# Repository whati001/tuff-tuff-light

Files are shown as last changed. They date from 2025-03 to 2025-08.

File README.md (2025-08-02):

# 🚜 Wireless BLE Trailer Light System for Tractors

A robust, modular, and completely wireless trailer lighting system designed for agricultural machinery, utilizing BLE communication. 
Built on the **nRF52840 SoC** and developed with the **Zephyr RTOS**, this project includes custom-designed PCBs and 3D printed enclosures for reliable field use.
The choose design enables seamless connectivity without complicated pairing procedures and also allows to connect up to infinite receiver lights to a single sender.  

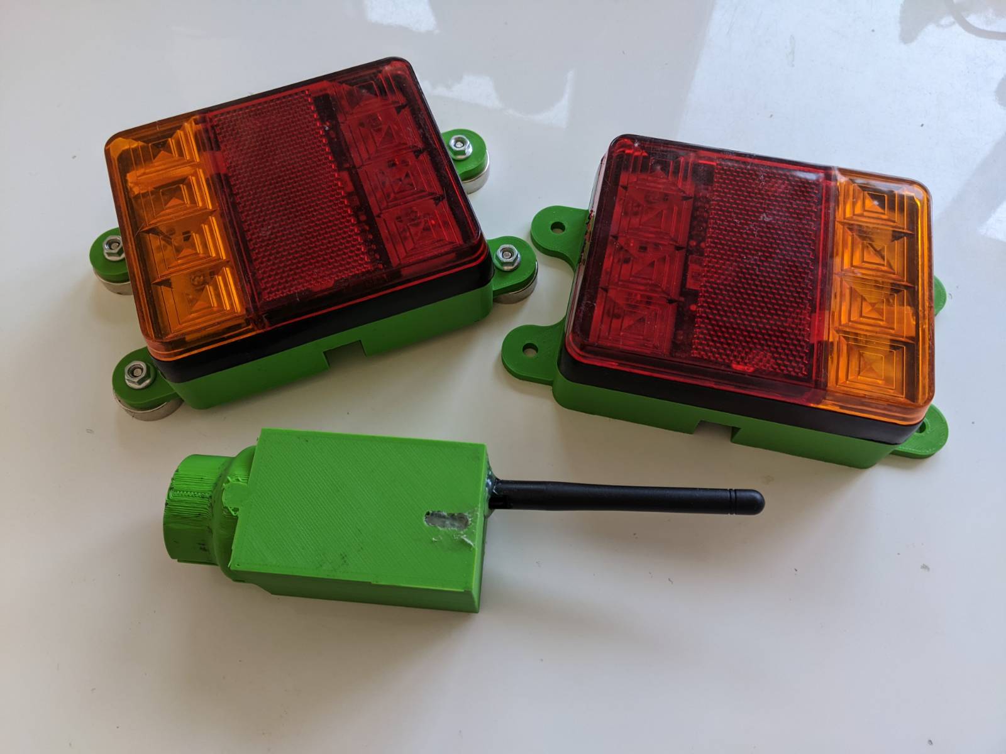
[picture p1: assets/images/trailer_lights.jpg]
Trailer Light Units

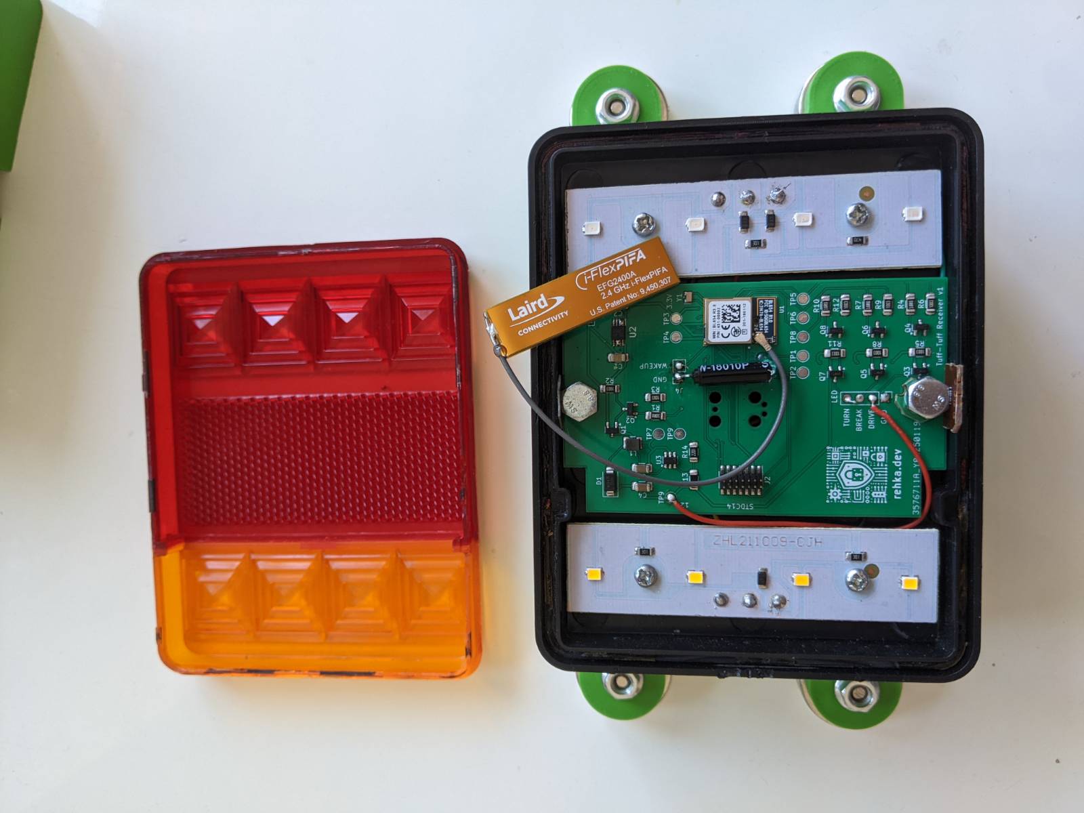
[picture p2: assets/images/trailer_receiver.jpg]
Trailer Light Receiver

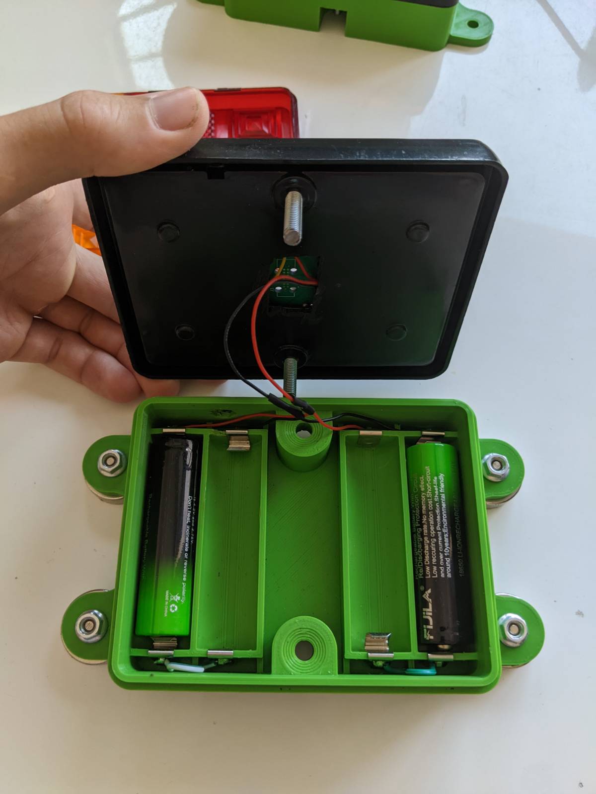
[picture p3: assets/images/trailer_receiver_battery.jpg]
Trailer Light Receiver Battery

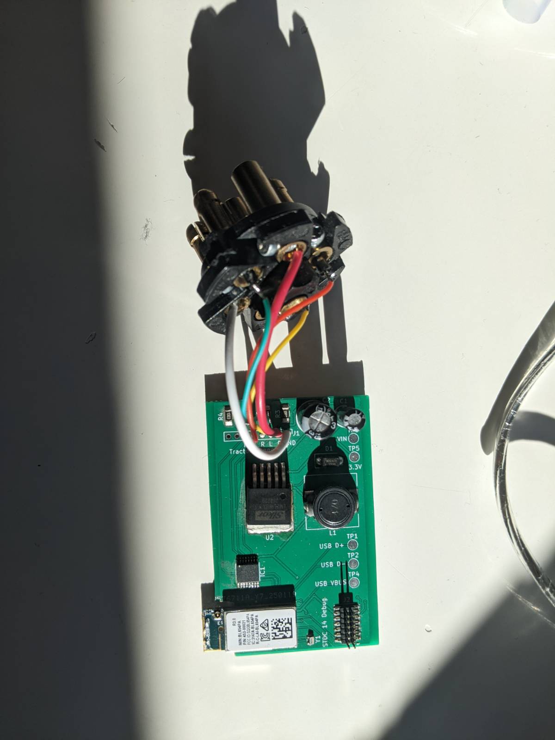
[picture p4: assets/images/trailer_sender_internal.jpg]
Trailer Light Sender Internal


TTL Demo (http://www.youtube.com/shorts/t9BFipJ9V28 "TTL Demonstration")

TTL Wakeup (http://www.youtube.com/watch?v=I9mE4fKHAj8 "TTL Wakeup")

## ✨ Features

- 🔋 Battery-powered light modules (18650 x 4)
- 📡 BLE-based communication (nRF52840)
- 🔧 Built with **Zephyr RTOS**
- 🔦 Fully functional red+amber light cluster with wireless control
- 🧲 Magnetic mounting for quick install/removal
- 💻 Custom 3D printed cases and two custom-designed PCBs
- 🧠 Intelligent Power Saving (auto wakeup, no need to "switch" the light on)
---

## 📦 Project Structure
The project is structured as follows.
```
.
├── 3d/             # 3d printer files
├── applications/ 
│ ├── ttl_sender/   # ttl sender code
│ └── ttl_receiver/ # ttl receiver code
├── boards/         # custom boards definition
├── pcb/            # custom pcb KiCad files
...
└── README.md
```

---

## 🚀 Getting Started

### 🛠️ Requirements

- [Zephyr SDK](https://docs.zephyrproject.org/latest/develop/getting_started/index.html)
- [West Tool](https://docs.zephyrproject.org/latest/develop/west/index.html)
- Python 3.8+
- USB debugger (J-Link or compatible)
- Custom PCB (JLC PCB + self assembly)

### 📥 1. Clone and Initialize
First we need to initiate a python environment and install west. Afterwards, we initiate the Zephyr workspace.
```bash
python -m venv ./env
<activate venv>
pip install west
west init -m https://github.com/whati001/tuff-tuff-light tuff_tuff_light
cd tuff_tuff_light
west update
```

### 🧪 2. Build the Firmware
Navigate into the workspace directory and run:

```
# build sender
west build -b ttlv1_pa/nrf52840 ttl/applications/ttl_sender

# build receiver
west build -b ttlv1/nrf52840 ttl/applications/ttl_sender
```

### 🔌 3. Flash the Devices

Connect your debugger and run:

```
west flash
```

## 📡 System Overview

Transmitter: Reads trailer socket signals and broadcasts light commands via BLE.
Receiver Modules: Interpret BLE commands and control LEDs accordingly.

## 🧩 Hardware Details

* PCBs
  * TX Board: Reads 4-pin trailer plug input, handles BLE communication.
  * RX Board: Contains BLE radio, LED drivers, battery power management.

* Enclosures
  * All parts are printed with PLA and designed for rugged outdoor use.
  * STL/STEP files are included in the 3d/ directory.

## 🧪 Testing and Validation

The project aims just to be a minimal viable project (MVP), so there is not much testing included.

## 📃 License

This project is licensed under the MIT License. See the LICENSE file for details.

## 🤝 Contributing

Contributions are welcome! If you'd like to add features (e.g., low battery warnings, OTA updates), feel free to open a PR or issue.
If you are interested to turn this MVP into a real project, please get in touch with me. 

## 🧭 Next Steps

Here are a few ideas and enhancements planned or recommended for future development:

🔋 Battery Charging
Currently, power is restored by manually replacing the 18650 batteries. The proposed improvement is to integrate a charging circuit directly into the 3D-printed enclosure, enabling in-place recharging and eliminating the need to open the housing. At the same time, the design would retain compatibility with swappable battery modules, allowing a quick base replacement in scenarios where charging time is a limiting factor.

🚦 Expanded Signal Set
Extend support for additional signal inputs from the standard 7-pin trailer connector, including reverse, brake, fog lights, and more. Furthermore, the system’s modular architecture enables the integration of entirely new light types, such as side marker lights (e.g., white delimiting lights along the trailer’s sides), enhancing both functionality and visibility.

🌧️ Weatherproofing Enhancements
Improve gasket seals in the 3D printed case and verify IP rating in outdoor environments.

📘 Documentation Expansion
Add detailed firmware architecture docs and schematic walkthroughs.

## 📬 Contact

For questions, suggestions, or demo requests, feel free to contact [whati001@outlook.com] or open a GitHub issue

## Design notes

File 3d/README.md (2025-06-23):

# 3D Printing Case

Please find the STL file for printing the case.
The original project is hosted on OnShape and accessible via this [link](https://cad.onshape.com/documents/57cf3ac100a7df695029e298/w/8071d1b9ffe831e105a828e7/e/94084472d73540d8294d81d9).

Unfortunately, the sender case was crated with Autodesk Fusion 360 and I lost access to my account.

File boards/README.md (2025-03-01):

# boards
This repository is intended to be added as a git submodule inside a Zephyr application directory.

```git submodule add git@github.com:Troposound/boards.git```

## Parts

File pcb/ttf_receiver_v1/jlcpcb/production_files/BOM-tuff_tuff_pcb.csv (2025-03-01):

Comment | Designator | Footprint | LCSC | Quantity
DMG2301L | Q1,Q3,Q5,Q7 | SOT-23 | C102619 | 4
10R | R1,R10,R4,R7 | R_1206_3216Metric_Pad1.30x1.75mm_HandSolder | C104606 | 4
2.2k | R14 | R_1206_3216Metric_Pad1.30x1.75mm_HandSolder | C114933 | 1
22u | C3,C4 | C_1206_3216Metric_Pad1.33x1.80mm_HandSolder | C12891 | 2
100k | R11,R12,R2,R3,R5,R6,R8,R9 | R_1206_3216Metric_Pad1.30x1.75mm_HandSolder | C17900 | 8
1u | C1 | C_1206_3216Metric_Pad1.33x1.80mm_HandSolder | C1848 | 1
42k | R13 | R_1206_3216Metric_Pad1.30x1.75mm_HandSolder | C229633 | 1
TLV76733QWDRBxQ1 | U2 | SOP65P490X110-9N | C2873382 | 1
Conn_ST_STDC14 | J2 | PinHeader_2x07_P1.27mm_Vertical_SMD | C41370775 | 1
2.2u | C2 | C_1206_3216Metric_Pad1.33x1.80mm_HandSolder | C50254 | 1
Crystal | Y1 | Crystal_SMD_MicroCrystal_CC8V-T1A-2Pin_2.0x1.2mm | C5142652 | 1
L22u | L1 | L_1210_3225Metric | C711136 | 1
451-00001 | U1 | XCVR_451-00001 | C7185357 | 1
MT3608 | U3 | SOT-23-6 | C84817 | 1
SS34 | D1 | D_SMA | C8678 | 1
DMG3402L | Q2,Q4,Q6,Q8 | SOT-23 | C96614 | 4
ON BOOSTER | TP9 | TestPoint_Pad_D2.0mm |  | 1

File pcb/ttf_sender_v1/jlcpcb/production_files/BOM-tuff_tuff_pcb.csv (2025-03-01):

Comment | Designator | Footprint | LCSC | Quantity
100k | R1,R2,R3,R4 | C_1206_3216Metric_Pad1.33x1.80mm_HandSolder | C17900 | 4
47u | L1 | L_12x12mm_H8mm | C2041853 | 1
CD74HC4050NSR | IC1 | TSSOP-16_4.4x5mm_P0.65mm | C352825 | 1
Conn_ST_STDC14 | J2 | PinHeader_2x07_P1.27mm_Vertical_SMD | C41370775 | 1
Crystal | Y1 | Crystal_SMD_MicroCrystal_CC8V-T1A-2Pin_2.0x1.2mm | C5142652 | 1
LM2596S-3.3 | U2 | TO-263-5_TabPin3 | C5186052 | 1
451-00001 | U1 | XCVR_451-00001 | C7185357 | 1
SS34 | D1 | D_SMA | C8678 | 1
100u | C1 | CP_Radial_D5.0mm_P2.00mm |  | 1
330u | C2 | CP_Radial_D8.0mm_P3.80mm |  | 1

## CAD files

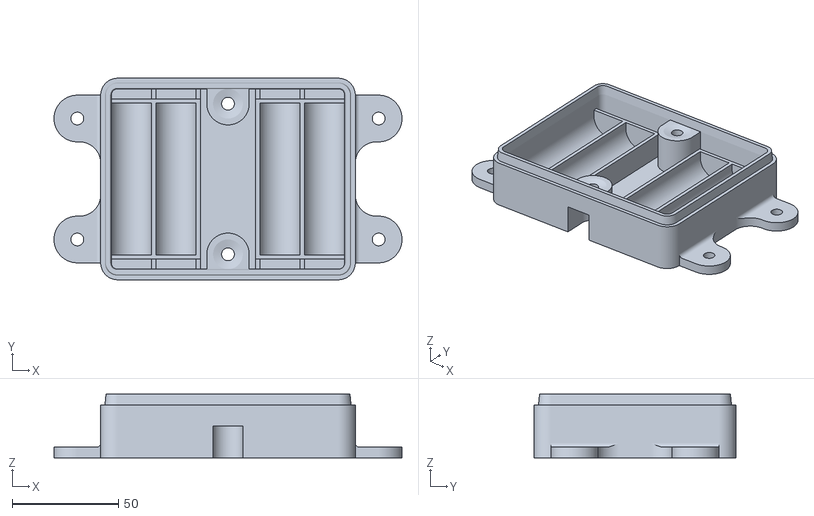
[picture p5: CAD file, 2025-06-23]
3d/ttl_base.stl
164.0 x 95.0 x 30.0

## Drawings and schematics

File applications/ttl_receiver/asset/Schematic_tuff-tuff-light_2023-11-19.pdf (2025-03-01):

## NRF Dongle

# GND GND VDD_OUT

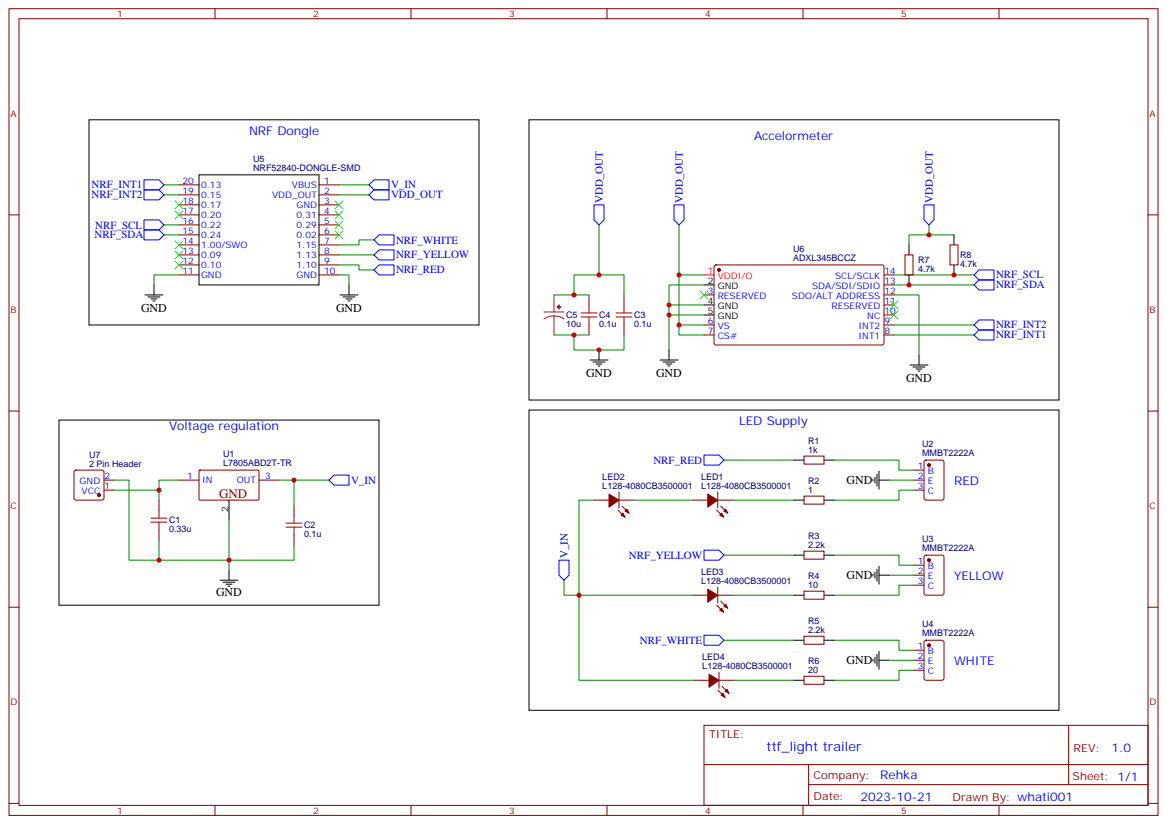
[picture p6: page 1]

ADXL345BCCZ
NC 10 RESERVED 11 SDO/ALT ADDRESS 12 SDA/SDI/SDIO 13 SCL/SCLK 14

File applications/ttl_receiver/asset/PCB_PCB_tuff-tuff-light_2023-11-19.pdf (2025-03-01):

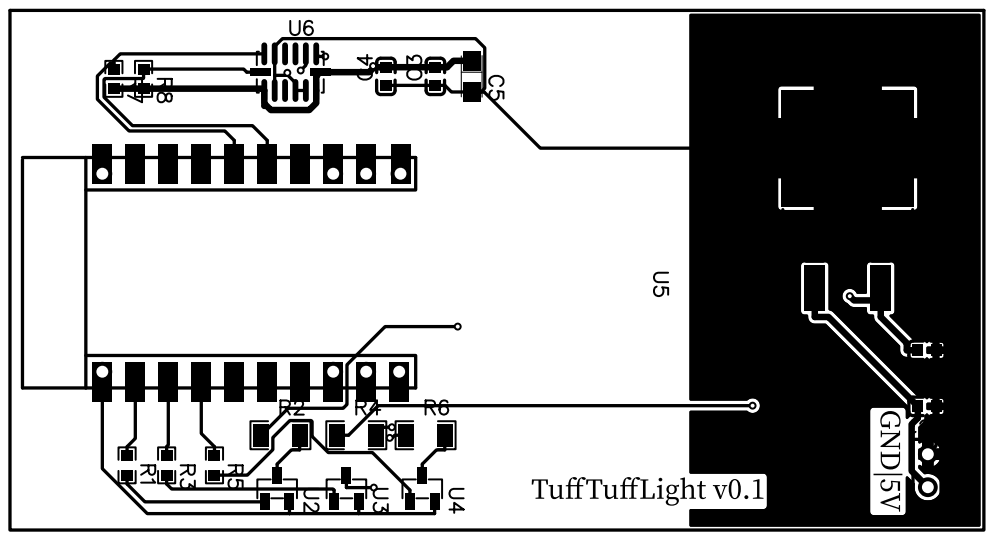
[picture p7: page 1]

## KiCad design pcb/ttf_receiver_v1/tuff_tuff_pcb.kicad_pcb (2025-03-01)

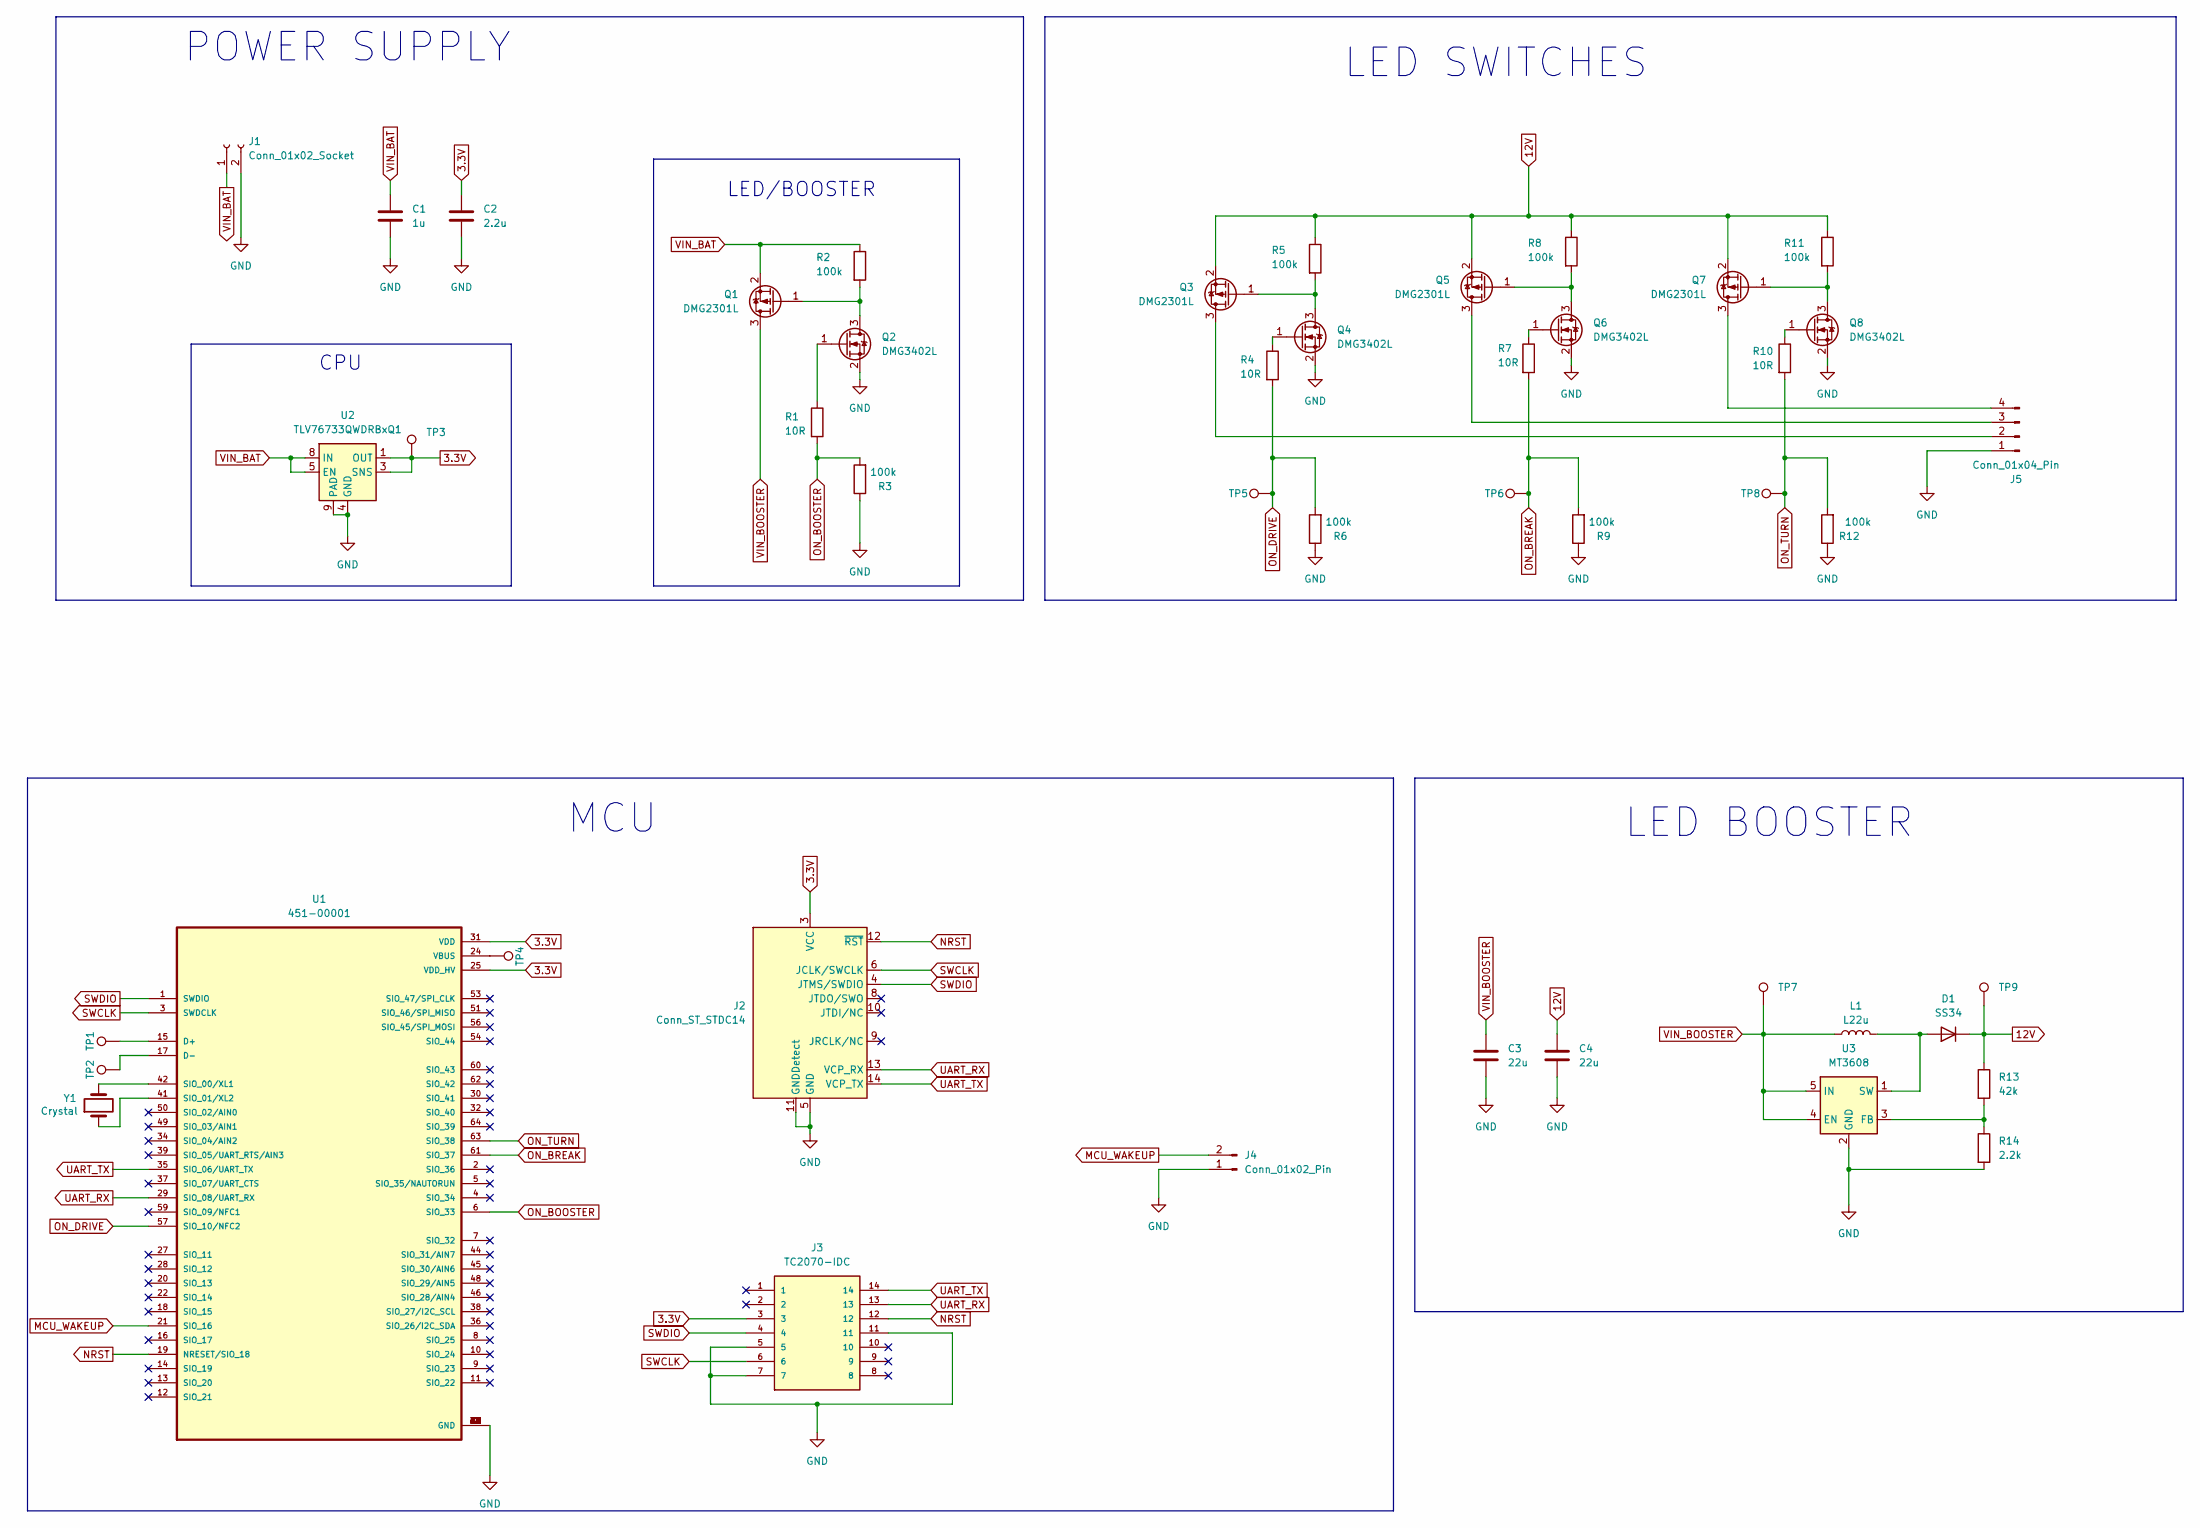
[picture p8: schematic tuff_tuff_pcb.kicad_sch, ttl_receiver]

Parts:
C1: 1u; C_1206_3216Metric_Pad1.33x1.80mm_HandSolder; LCSC C1848
C2: 2.2u; C_1206_3216Metric_Pad1.33x1.80mm_HandSolder; LCSC C50254
C3, C4: 22u; C_1206_3216Metric_Pad1.33x1.80mm_HandSolder; LCSC C12891
D1: SS34; D_SMA; LCSC C8678
J1: Conn_01x02_Socket; PinHeader_1x02_P2.54mm_Vertical
J2: Conn_ST_STDC14; PinHeader_2x07_P1.27mm_Vertical_SMD; LCSC C41370775
J3: TC2070-IDC; TAG-CONNECT_TC2070-IDC
J4: Conn_01x02_Pin; PinSocket_1x02_P2.54mm_Vertical
J5: Conn_01x04_Pin; PinHeader_1x04_P2.54mm_Vertical
L1: L22u; L_1210_3225Metric; LCSC C711136
Q1, Q3, Q5, Q7: DMG2301L; SOT-23; LCSC C102619
Q2, Q4, Q6, Q8: DMG3402L; SOT-23; LCSC C96614
R1, R4, R7, R10: 10R; R_1206_3216Metric_Pad1.30x1.75mm_HandSolder; LCSC C104606
R2, R3, R5, R6, R8, R9, R11, R12: 100k; R_1206_3216Metric_Pad1.30x1.75mm_HandSolder; LCSC C17900
R13: 42k; R_1206_3216Metric_Pad1.30x1.75mm_HandSolder; LCSC C229633
R14: 2.2k; R_1206_3216Metric_Pad1.30x1.75mm_HandSolder; LCSC C114933
TP1, TP2, TP3, TP4, TP5, TP6, TP8: TestPoint; TestPoint_Pad_D2.0mm
TP7: IN BOOSTER; TestPoint_Pad_D2.0mm
TP9: OUT BOOSTER; TestPoint_Pad_D2.0mm
U1: 451-00001; XCVR_451-00001; Mouser Part# 814-451-00002
U2: TLV76733QWDRBxQ1; SOP65P490X110-9N; LCSC C2873382
U3: MT3608; SOT-23-6; LCSC C84817
Y1: Crystal; Crystal_SMD_MicroCrystal_CC8V-T1A-2Pin_2.0x1.2mm; Mouser Part# 428-201410-MC01

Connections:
3.3V: C2.1, J2.3 (VCC), J3.3, TP3.1, U1.25 (VDD_HV), U1.31 (VDD), U2.1 (OUT), U2.3 (SNS)
12V: C4.1, D1.1 (K), Q3.2 (S), Q5.2 (S), Q7.2 (S), R5.1, R8.1, R11.1, R13.1, TP9.1
GND: C1.2, C2.2, C3.2, C4.2, J1.2, J2.5 (GND), J2.7 (GND), J2.11 (GNDDetect), J3.5, J3.7, J3.11, J4.1, J5.1, Q2.2 (S), Q4.2 (S), Q6.2 (S), Q8.2 (S), R3.1, R6.1, R9.1, R12.1, R14.2, U1.0 (GND), U1.23 (GND), U1.26 (GND), U1.33 (GND), U1.40 (GND), U1.43 (GND), U1.47 (GND), U1.52 (GND), U1.55 (GND), U1.58 (GND), U1.65 (GND), U1.66 (GND), U1.67 (GND), U1.68 (GND), U1.69 (GND), U1.70 (GND), U1.71 (GND), U2.4 (GND), U2.6 (GND), U2.9 (PAD), U3.2 (GND)
MCU_WAKEUP: J4.2, U1.21 (SIO_16)
NRST: J2.12 (~RST), J3.12, U1.19 (NRESET/SIO_18)
unnamed: D1.2 (A), L1.2, U3.1 (SW)
unnamed: J5.2, Q3.3 (D)
unnamed: J5.3, Q5.3 (D)
unnamed: J5.4, Q7.3 (D)
unnamed: Q1.1 (G), Q2.3 (D), R2.2
unnamed: Q2.1 (G), R1.1
unnamed: Q3.1 (G), Q4.3 (D), R5.2
unnamed: Q4.1 (G), R4.1
unnamed: Q5.1 (G), Q6.3 (D), R8.2
unnamed: Q6.1 (G), R7.1
unnamed: Q7.1 (G), Q8.3 (D), R11.2
unnamed: Q8.1 (G), R10.1
unnamed: TP1.1, U1.15 (D+)
unnamed: TP2.1, U1.17 (D-)
unnamed: U1.42 (SIO_00/XL1), Y1.2
unnamed: U1.41 (SIO_01/XL2), Y1.1
unnamed: TP4.1, U1.24 (VBUS)
unnamed: R13.2, R14.1, U3.3 (FB)
ON_BOOSTER: R1.2, R3.2, U1.6 (SIO_33); also elsewhere on the board
ON_BREAK: R7.2, R9.2, TP6.1, U1.61 (SIO_37)
ON_DRIVE: R4.2, R6.2, TP5.1, U1.57 (SIO_10/NFC2)
ON_TURN: R10.2, R12.2, TP8.1, U1.63 (SIO_38)
SWCLK: J2.6 (JCLK/SWCLK), J3.6, U1.3 (SWDCLK)
SWDIO: J2.4 (JTMS/SWDIO), J3.4, U1.1 (SWDIO)
UART_RX: J2.13 (VCP_RX), J3.13, U1.29 (SIO_08/UART_RX)
UART_TX: J2.14 (VCP_TX), J3.14, U1.35 (SIO_06/UART_TX)
VIN_BAT: C1.1, J1.1, Q1.2 (S), R2.1, U2.5 (EN), U2.8 (IN)
VIN_BOOSTER: C3.1, L1.1, Q1.3 (D), TP7.1, U3.4 (EN), U3.5 (IN)

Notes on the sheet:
LED/BOOSTER
LED BOOSTER
MCU
CPU
LED SWITCHES
POWER SUPPLY

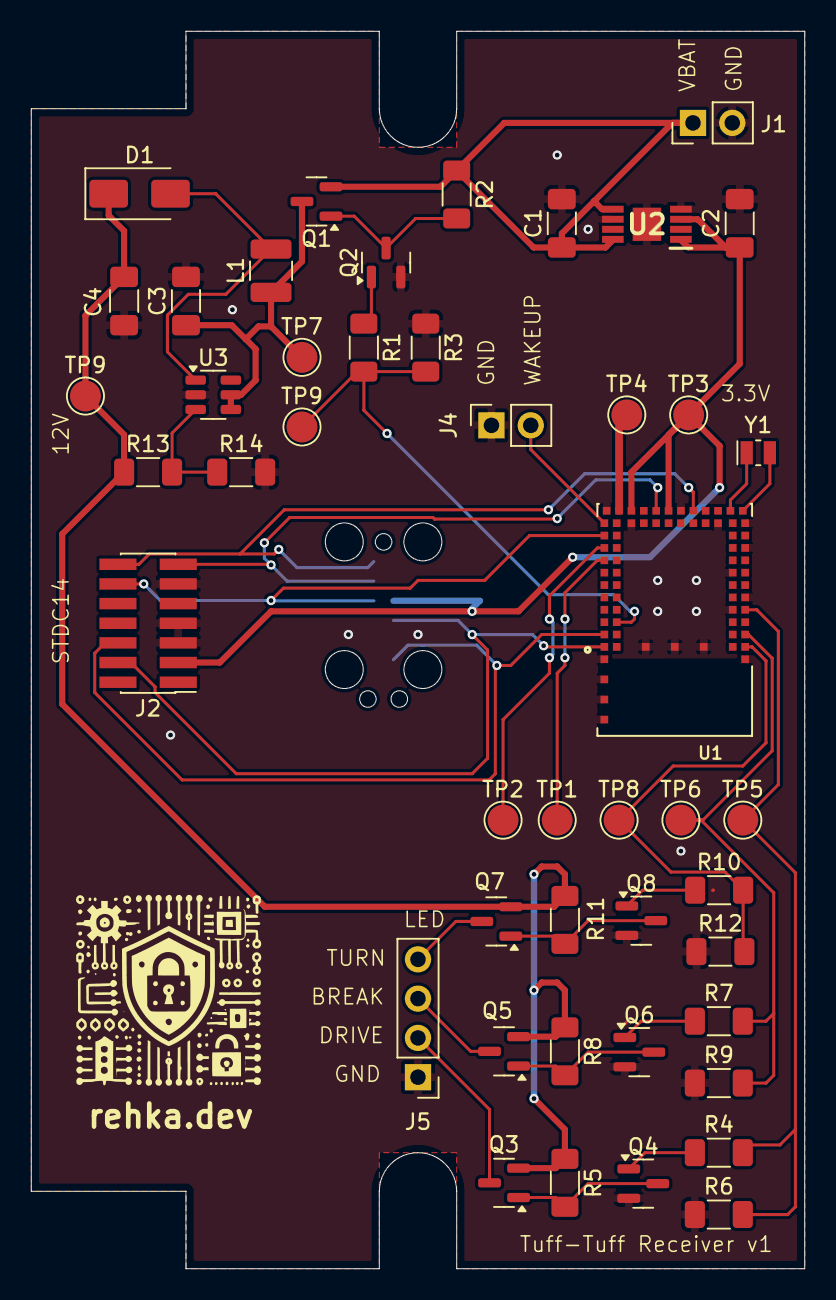
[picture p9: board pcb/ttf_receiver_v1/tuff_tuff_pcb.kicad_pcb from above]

Board: 2 copper layers, 50.0 x 80.0 mm, 47 parts (1 on the bottom side), 33 nets.

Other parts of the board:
TP9#2: ON BOOSTER; TestPoint_Pad_D2.0mm

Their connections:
ON_BOOSTER: TP9#2.1; also elsewhere on the board

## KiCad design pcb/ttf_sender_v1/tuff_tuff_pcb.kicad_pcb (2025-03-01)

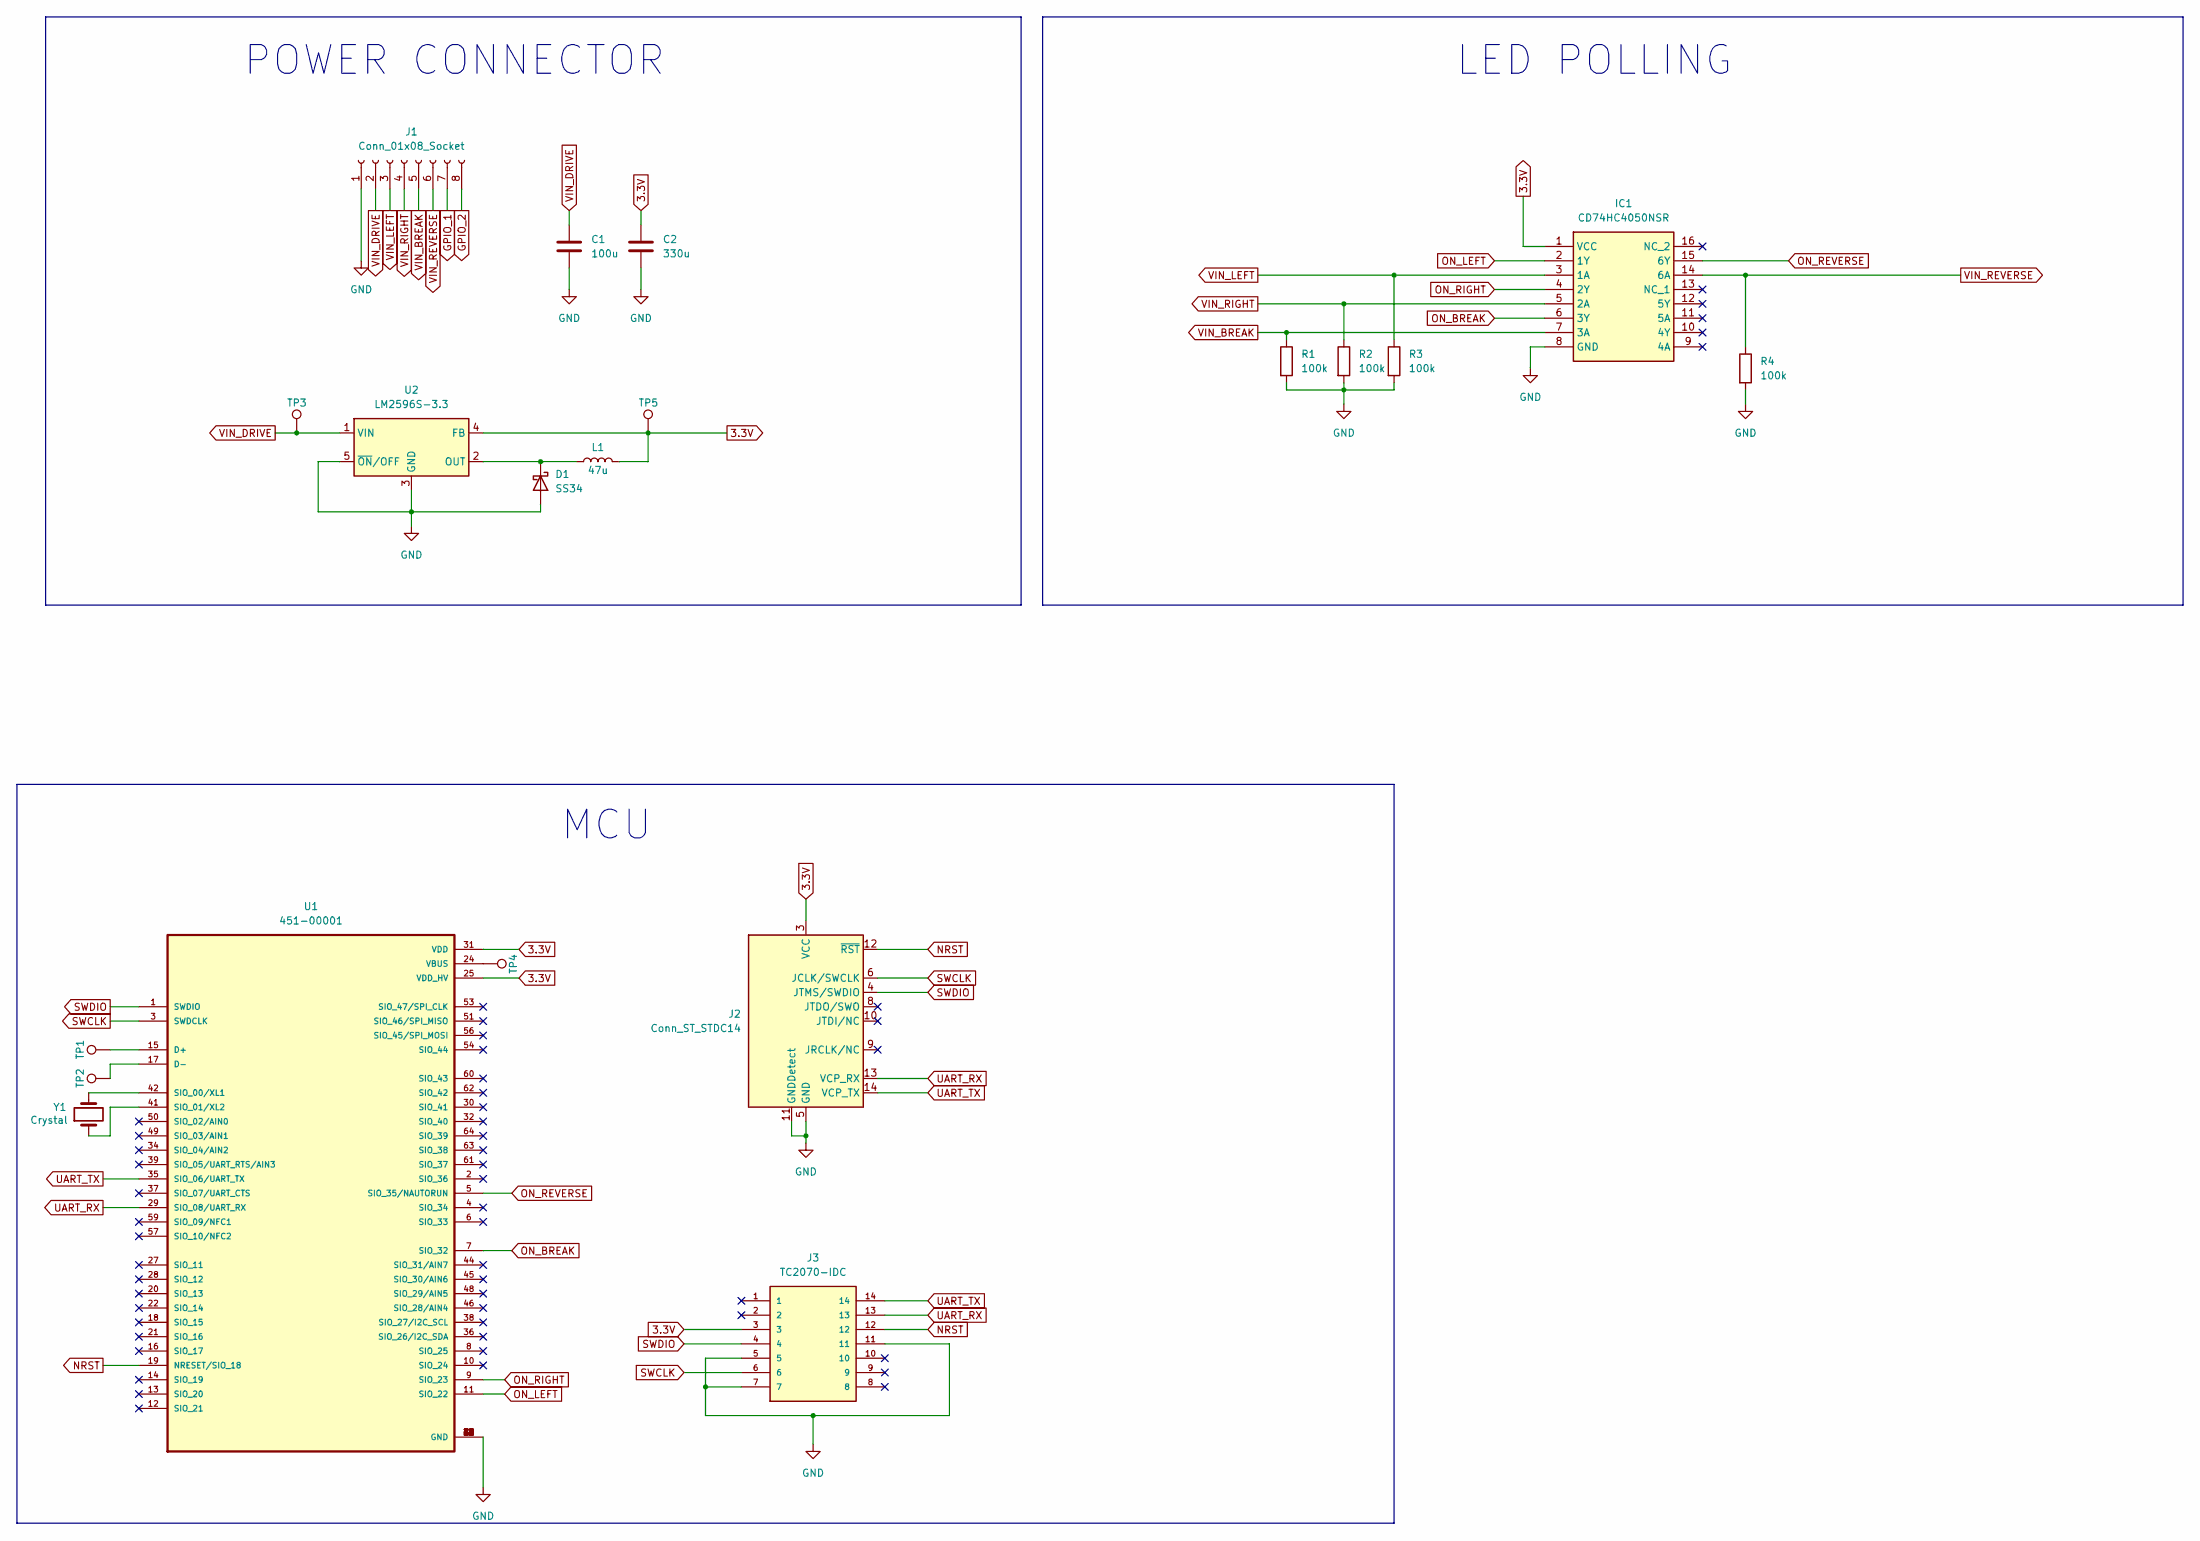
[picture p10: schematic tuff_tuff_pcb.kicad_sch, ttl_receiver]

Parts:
C1: 100u; CP_Radial_D5.0mm_P2.00mm; Part# at home
C2: 330u; CP_Radial_D8.0mm_P3.80mm; Part# at home
D1: SS34; D_SMA; LCSC C8678
IC1: CD74HC4050NSR; TSSOP-16_4.4x5mm_P0.65mm; Mouser Part Number 595-CD74HC4050NSR
J1: Conn_01x08_Socket; PinHeader_1x08_P2.00mm_Vertical
J2: Conn_ST_STDC14; PinHeader_2x07_P1.27mm_Vertical_SMD; LCSC C41370775
J3: TC2070-IDC; TAG-CONNECT_TC2070-IDC
L1: 47u; L_12x12mm_H8mm; LCSC C2041853
R1, R2, R3: 100k; C_1206_3216Metric_Pad1.33x1.80mm_HandSolder; LCSC C17900
R4: 100k; C_1206_3216Metric_Pad1.33x1.80mm_HandSolder; LCSC Part# C4107364
TP1, TP2, TP3, TP4, TP5: TestPoint; TestPoint_Pad_D2.0mm
U1: 451-00001; XCVR_451-00001; Mouser Part# 814-451-00002
U2: LM2596S-3.3; TO-263-5_TabPin3; LCSC C5186052
Y1: Crystal; Crystal_SMD_MicroCrystal_CC8V-T1A-2Pin_2.0x1.2mm; Mouser Part# 428-201410-MC01

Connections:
3.3V: C2.1, IC1.1 (VCC), J2.3 (VCC), J3.3, L1.2, TP5.1, U1.25 (VDD_HV), U1.31 (VDD), U2.4 (FB)
GND: C1.2, C2.2, D1.2 (A), IC1.8 (GND), J1.1, J2.5 (GND), J2.7 (GND), J2.11 (GNDDetect), J3.5, J3.7, J3.11, R1.2, R2.2, R3.2, R4.2, U1.0 (GND), U1.23 (GND), U1.26 (GND), U1.33 (GND), U1.40 (GND), U1.43 (GND), U1.47 (GND), U1.52 (GND), U1.55 (GND), U1.58 (GND), U1.65 (GND), U1.66 (GND), U1.67 (GND), U1.68 (GND), U1.69 (GND), U1.70 (GND), U1.71 (GND), U2.3 (GND), U2.5 (~ON/OFF)
GPIO_1: J1.7
GPIO_2: J1.8
NRST: J2.12 (~RST), J3.12, U1.19 (NRESET/SIO_18)
unnamed: D1.1 (K), L1.1, U2.2 (OUT)
unnamed: TP1.1, U1.15 (D+)
unnamed: TP2.1, U1.17 (D-)
unnamed: U1.42 (SIO_00/XL1), Y1.2
unnamed: U1.41 (SIO_01/XL2), Y1.1
unnamed: TP4.1, U1.24 (VBUS)
ON_BREAK: IC1.6 (3Y), U1.7 (SIO_32)
ON_LEFT: IC1.2 (1Y), U1.11 (SIO_22)
ON_REVERSE: IC1.15 (6Y), U1.5 (SIO_35/NAUTORUN)
ON_RIGHT: IC1.4 (2Y), U1.9 (SIO_23)
SWCLK: J2.6 (JCLK/SWCLK), J3.6, U1.3 (SWDCLK)
SWDIO: J2.4 (JTMS/SWDIO), J3.4, U1.1 (SWDIO)
UART_RX: J2.13 (VCP_RX), J3.13, U1.29 (SIO_08/UART_RX)
UART_TX: J2.14 (VCP_TX), J3.14, U1.35 (SIO_06/UART_TX)
VIN_BREAK: IC1.7 (3A), J1.5, R1.1
VIN_DRIVE: C1.1, J1.2, TP3.1, U2.1 (VIN)
VIN_LEFT: IC1.3 (1A), J1.3, R3.1
VIN_REVERSE: IC1.14 (6A), J1.6, R4.1
VIN_RIGHT: IC1.5 (2A), J1.4, R2.1

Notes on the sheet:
MCU
LED POLLING
POWER CONNECTOR

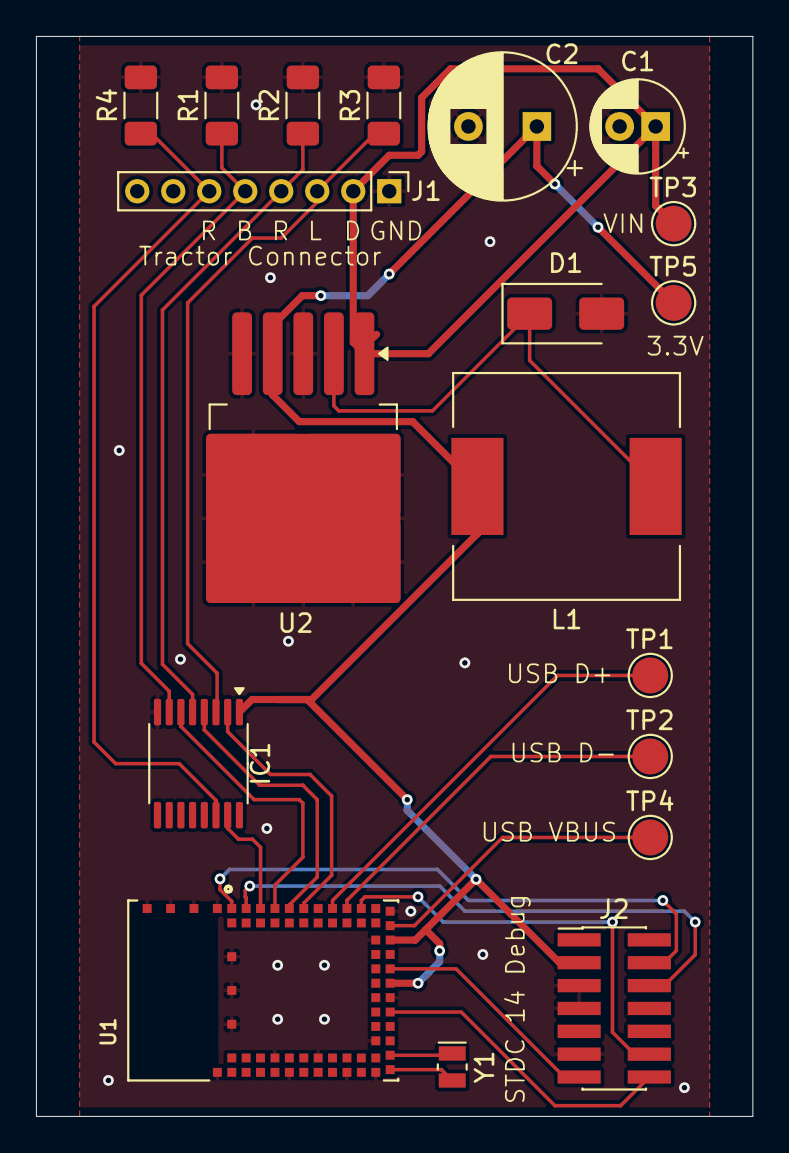
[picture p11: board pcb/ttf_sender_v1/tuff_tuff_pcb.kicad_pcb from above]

Board: 2 copper layers, 39.8 x 60.0 mm, 19 parts (0 on the bottom side), 22 nets.

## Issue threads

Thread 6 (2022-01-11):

Central inverts the listener state from time to time

whati001, 2022-01-11:
If we trigger multiple time the same gpio port, somehow the central inverts the state and we disable for example the break instead of activating.

whati001, 2022-01-11:
We assume, this is somehow related with the interrupt de-bouncing. Because the current code sends out the new state within in while loop sitting in the main with an 50ms interval, the easiest fix is to switch back to polling mode.
This will introduce a overall delay of 50ms + the transmission duration.
Polling is not a nice solution, however it fixes this issue and also allows to relax the debouncing of the gpios a bit.

whati001, 2022-01-11:
Please see pr #7, we moved back to polling the gpio ports again.
This should fix the issue #6 and also works nicer than the interrupt mode. We can simply use the polling, because nothing else is running on the central. In addition, scanning and connecting to peripherals also still works.
You can define if you want to use interrupt of non-interrupt mode by setting the define value GPIO_INTERRUPT

Closed 2022-01-11.

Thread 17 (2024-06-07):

receiver: No CPU wakeup by accel sensor if triggered before 2 seconds

whati001, 2024-06-07:
The current receiver logic configures the CPU wake up logic, sleeps two seconds for cool down, and goes to sleep afterwards. This means, if the accel triggers the interrupt within these two seconds of cool down, the CPU does not reset the interrupt and the interrupt line remains high once the receiver goes to sleep. This implies that no new interrupt can be triggered by the accel and the receiver must be reset via battery.

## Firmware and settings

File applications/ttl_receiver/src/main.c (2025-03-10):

#include <stdint.h>
#include <zephyr/drivers/gpio.h>
#include <zephyr/drivers/sensor.h>
#include <zephyr/kernel.h>
#include <zephyr/logging/log.h>
#include <zephyr/sys/poweroff.h>
#include <zephyr/sys/reboot.h>

#include "ble.h"
#include "led.h"
#include "ttl.h"

LOG_MODULE_REGISTER(ttl_main, LOG_LEVEL_INF);

/**
 * @brief Reset pin, used by spring resistor to wakeup the boot
 */
static const struct gpio_dt_spec reboot_pin =
    GPIO_DT_SPEC_GET(DT_NODELABEL(reboot_pin), gpios);

/**
 * @brief Reset pin, used by the accelerometer to wakeup the boot
 */
static const struct gpio_dt_spec booster_enable_pin =
    GPIO_DT_SPEC_GET(DT_NODELABEL(booster_pin), gpios);

/**
 * @brief Overwrite ASSERT handler
 * @param reason - The reason for the fatal error
 * @param esf    - Exception context, with details and partial or full register
 *                 state when the error occurred. May in some cases be NULL.
 */
void k_sys_fatal_error_handler(unsigned int reason, const z_arch_esf_t *esf) {
  ARG_UNUSED(esf);
  LOG_ERR("Assert received, reboot system");
  sys_reboot(SYS_REBOOT_COLD);
  CODE_UNREACHABLE; /* LCOV_EXCL_LINE */
}

/**
 * @brief Power down TTL to save energy.
 * This function activates the acceleration monitoring and wakeups the MCU once
 * a movement is recognized.
 */
static int ttl_power_down() {
  int err;

  // stop all components
  ttl_ble_terminate();
  ttl_led_terminate();
  LOG_INF("Shutting down the system");

  // disable booster for leds
  err = gpio_pin_set_dt(&booster_enable_pin, 0);
  if (err < 0) {
    LOG_ERR("Could not enable booster GPIO (%d)\n", err);
    return TTL_ERR;
  }

  // wait some time before shuting down the system
  k_msleep(2000);

  // overwrite gpio interrupt pin config to be a user wakeup pin
  err = gpio_pin_configure_dt(&reboot_pin, GPIO_INPUT);
  if (err < 0) {
    LOG_ERR("Could not configure sw0 GPIO (%d)\n", err);
    return TTL_ERR;
  }

  err = gpio_pin_interrupt_configure_dt(&reboot_pin, GPIO_INT_LEVEL_ACTIVE);
  if (err < 0) {
    LOG_ERR("Could not configure sw0 GPIO interrupt (%d)\n", err);
    return TTL_ERR;
  }

  sys_poweroff();

  return TTL_OK;
}

/**
 * @brief Main function of the TTL receiver
 */
int main(void) {
  ttl_err_t err = 0;
  int64_t last_packet_time_ms;
  int64_t elapsed_time_ms;

  LOG_INF("Starting TTLight Controller\n");

  err = ttl_ble_init();
  if (TTL_OK != err) {
    LOG_ERR("Failed to initialize the TTLight BLE stack\n");
    return TTL_ERR;
  }
  LOG_INF("Initialized TTLight BLE stack properly");

  err = ttl_led_init();
  if (TTL_OK != err) {
    LOG_ERR("Failed to initialize the TTLight GPIO stack\n");
    goto exit;
  }
  ttl_ble_register_cb(ttl_led_upd_status);
  LOG_INF("Initialized TTLight LED stack properly");

  err = ttl_led_run();
  if (TTL_OK != err) {
    LOG_ERR("Failed to start TTLight LED stack");
    return TTL_ERR;
  }
  LOG_INF("Started TTLight LED stack properly");

  err = ttl_ble_run();
  if (TTL_OK != err) {
    LOG_ERR("Failed to start TTLight BLE stack");
    return TTL_ERR;
  }
  LOG_INF("Started TTLight BLE stack properly");

  // enable booster for leds
  err = gpio_pin_configure_dt(&booster_enable_pin, GPIO_OUTPUT);
  if (err < 0) {
    LOG_ERR("Could not configure booster GPIO (%d)\n", err);
    return TTL_ERR;
  }
  err = gpio_pin_set_dt(&booster_enable_pin, 1);
  if (err < 0) {
    LOG_ERR("Could not enable booster GPIO (%d)\n", err);
    return TTL_ERR;
  }

exit:
  while (1) {
    last_packet_time_ms = ttl_ble_latest_packet_datetime_ms();
    elapsed_time_ms = k_uptime_delta(&last_packet_time_ms);
    LOG_INF("Elapsed time(ms): %lld", elapsed_time_ms);
    k_msleep(1000);

    if (elapsed_time_ms > (CONFIG_TTL_SHUTDOWN_TIMEOUT_SEC * 1000)) {
      err = ttl_power_down();
      if (TTL_OK != err) {
        LOG_ERR("Failed to shutdown, let's force a restart of the board");
        k_msleep(2000);
        sys_reboot(SYS_REBOOT_COLD);
      }
    }
  }
  return 0;
}

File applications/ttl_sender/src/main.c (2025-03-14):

#include <zephyr/kernel.h>
#include <zephyr/logging/log.h>

#include "ble.h"
#include "gpio.h"
#include "ttl.h"

LOG_MODULE_REGISTER(ttl_main, LOG_LEVEL_INF);

int main(void) {
  ttl_err_t ret = 0;
  LOG_INF("Initiating TTLight Controller\n");

  ret = ttl_ble_init();
  if (TTL_OK != ret) {
    LOG_ERR("Failed to initialize the TTLight BLE stack");
    return ret;
  }

  ret = ttl_gpio_init();
  if (TTL_OK != ret) {
    LOG_ERR("Failed to initialize the TTLight GPIO stack");
    return ret;
  }
  ttl_gpio_register_cb(ttl_ble_upd_status);

  ret = ttl_gpio_run();
  if (TTL_OK != ret) {
    LOG_ERR("Failed to start continuously TTLState sampling");
    return TTL_ERR;
  }

  ret = ttl_ble_run();
  if (TTL_OK != ret) {
    LOG_ERR(
        "Failed to start continuously sending current TTL state via    BLE\n");
    return TTL_ERR;
  }

  while (1) {
    LOG_INF("TTLight Controller is running\n");
    k_sleep(K_MSEC(1000));
  }
  return TTL_OK;
}

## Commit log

2025-03-01 feat: Added ttl sender v1 board definition
2025-03-01 feat: Added version 1 pcb kicad files
    [BOM-tuff_tuff_pcb.csv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]
2025-03-09 feat: Added new ttl board definition
2025-03-09 feat: Ported ttl receiver to new board
2025-03-09 feat: Updated ttl schematic
    [tuff_tuff_pcb.kicad_sch]
2025-03-10 feat: Updated ttl sender code to match new zephyr iso sample
2025-03-14 fix(sender): Updated sender code to work again
    [main.c]
2025-06-22 fix: Updated board overlay files
    [led.c]
2025-06-23 feat: Added receiver case stl file
    [ttl_base.stl]
